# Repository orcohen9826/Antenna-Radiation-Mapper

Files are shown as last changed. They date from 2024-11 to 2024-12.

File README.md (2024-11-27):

# Antenna Radiation Mapper

## Overview

The **Antenna Radiation Mapper** is a versatile tool for mapping antenna radiation patterns with high precision. This project provides an affordable solution for testing antennas, including parabolic reflectors, offering a straightforward setup and simple operation. The system combines automated data collection, precise antenna movement, and easy connectivity, making it ideal for both enthusiasts and professionals looking for an effective antenna testing tool.

Note: This project does not include signal processing features, as they are part of a separate project that cannot be disclosed. Feel free to implement your own signal processing methods if needed.

## Key Features

- **Precision Control:** Rotate the antenna with high precision (approximately 310 steps per degree).
- **Automated Measurements:** Handle sampling, gain calculations, and graph generation.
- **Connectivity:** Connect over WiFi or serial port for data collection.
- **Modular Design:** Easily swap antennas for testing different configurations.

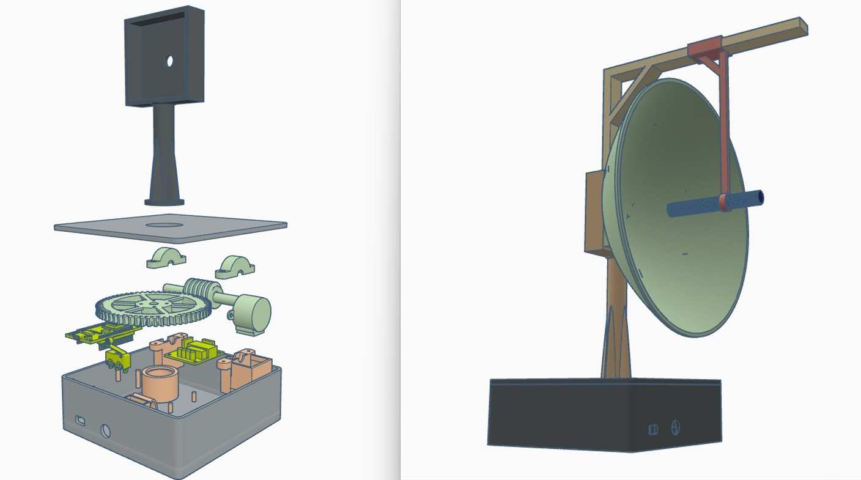
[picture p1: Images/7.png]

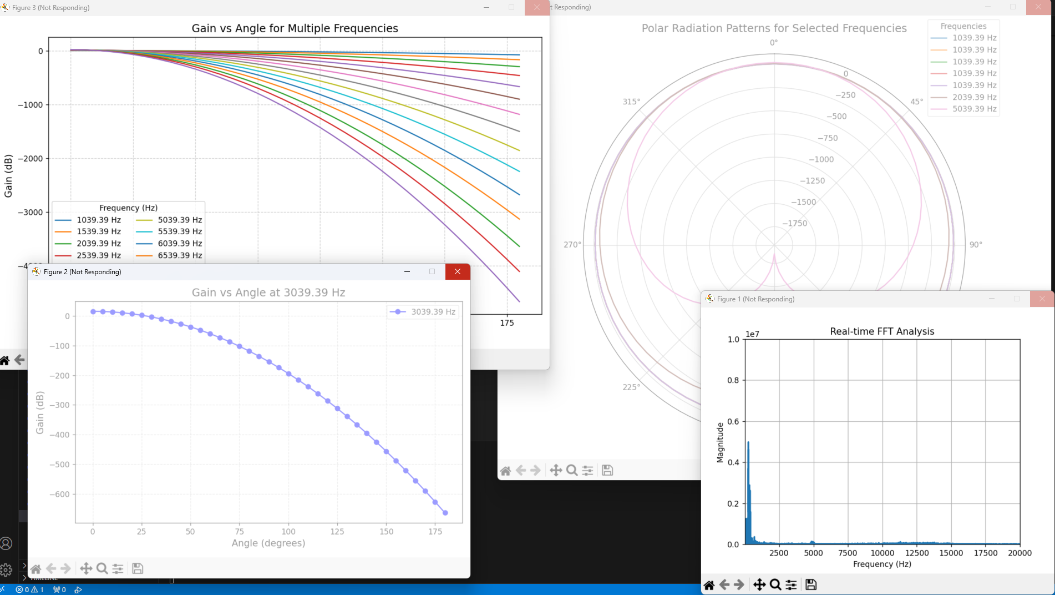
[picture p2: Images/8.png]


## Components Needed

To build your own Antenna Radiation Mapper, you will need the following components:

- **Stepper Motor:**  28BYJ-48
- **Motor Driver:** ULN2003AN
- **Microcontroller:** NodeMCU V3 (ESP8266-based)
- **Bearings:** 4 x Bearings
- **Bolts & Nuts:** 4 x M3*10 Bolts, 4 x M3 Nuts
- **Micro Switch:** 1 Micro Switch

You’ll also need to print some custom-designed 3D parts, which are provided as STL files in the repository.

## Mechanical Setup

1. **3D Print the Required Parts:** Print all parts using the STL files located in the [STL Files Folder](STL_Files).
2. **Attach Bearings:** Insert the 4 bearings into the appropriate printed parts.

## Wiring Instructions

1. **Stepper Motor Wiring:**
   - **IN1:** Connect to pin **D1** on the NodeMCU.
   - **IN2:** Connect to pin **D2** on the NodeMCU.
   - **IN3:** Connect to pin **D3** on the NodeMCU.
   - **IN4:** Connect to pin **D4** on the NodeMCU.

2. **Micro Switch Wiring:**
   - Connect the micro switch to **LIMIT\_SWITCH\_PIN (D5)** on the NodeMCU.

3. **Power Supply:**
   - Provide power to both the driver and the NodeMCU. Ensure that they **share a common ground**.

## Software Setup

1. **Download the Code:** Clone or download the code from this repository.
2. **Microcontroller Code:** Flash the C code to the NodeMCU V3 using [PlatformIO](https://platformio.org/) or the Arduino IDE.
3. **Python Script for Serial Communication:** There is a Python script available in the repository that allows you to connect via serial communication and initiate antenna movements and data recordings.

## Explanation of Files

- **`main.cpp` (Microcontroller Control Code):**
  - This file contains the code for controlling the stepper motor using the NodeMCU. It also provides a web interface accessible at **192.168.4.1** once connected to the WiFi broadcast by the NodeMCU. Users can enter desired angles and control the movement of the antenna through this interface. The script manages commands like moving the antenna, setting a zero (home) position, and pausing.

- **`serial_audio_recorder.py` (Audio Recording and Analysis Script):**
  - This Python script is used to communicate with the microcontroller via serial connection. It listens for commands indicating specific positions (like "Start brake" and "End brake") and then records audio for each of these positions. The script also performs FFT (Fast Fourier Transform) analysis on the recorded audio to determine the frequency response of the antenna and saves these results to a CSV file (`frequency_analysis.csv`).

- **`graphFromCsv.py` (Graph Generation Script):**
  - This script takes the CSV file generated by `serial_audio_recorder.py` and generates graphs to visualize the antenna's performance. It provides functions to plot gain vs. angle for individual frequencies, as well as generate polar radiation patterns. This helps in understanding how the antenna performs at different frequencies and in different directions.

## Getting Started

1. **Power Up:** Make sure the driver, NodeMCU, and micro switch are powered properly.
2. **Connect to WiFi:** Connect to the WiFi network broadcasted by the NodeMCU. Once connected, access the control interface by navigating to **192.168.4.1** in your web browser.
3. **Initiate Testing:** Run the Python script (`serial_audio_recorder.py`) to communicate with the NodeMCU either via WiFi or using a serial connection.
4. **Recording and Analysis:** The Python script will automatically record audio and perform analysis whenever the motor movement pauses. Once testing is complete, the `graphFromCsv.py` script will generate graphs and analyze the antenna's radiation patterns.

## What to Expect

- **Web Interface Control:** You'll be able to control the antenna's movement using a simple web interface. Set the target angle, step size, and delay, and monitor the current position in real-time.
- **Audio Recording and Analysis:** The script records audio at each position, performs FFT to analyze signal properties, and saves the frequency response data to a CSV file.
- **Visual Data Representation:** After collecting data, run the `graphFromCsv.py` script to generate informative visualizations, including gain vs. angle graphs and polar plots. These visualizations will help you evaluate the radiation pattern of the antenna and determine its performance at different frequencies.

## Contributing

If you have any ideas for improving the project, feel free to open a pull request or submit an issue. Contributions are always welcome!

## License

This project is licensed under the MIT License. See the LICENSE file for more details.

## Contact

If you have any questions or issues with the setup, feel free to contact me through GitHub.

Enjoy building your own **Antenna Radiation Mapper**!

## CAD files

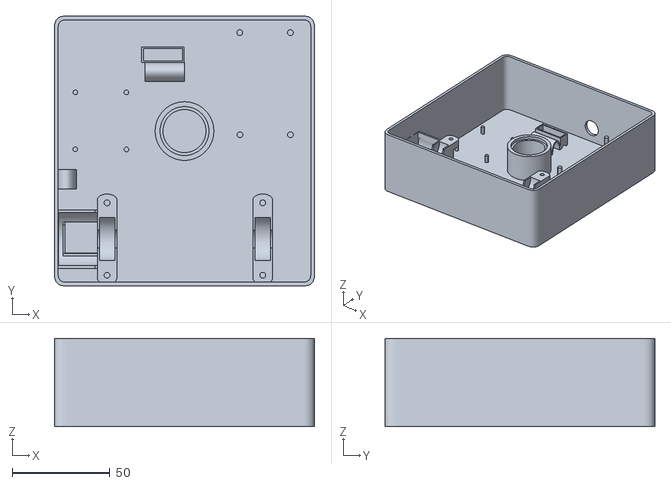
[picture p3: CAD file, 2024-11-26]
STL files/Main Box.stl
133.0 x 138.0 x 45.0

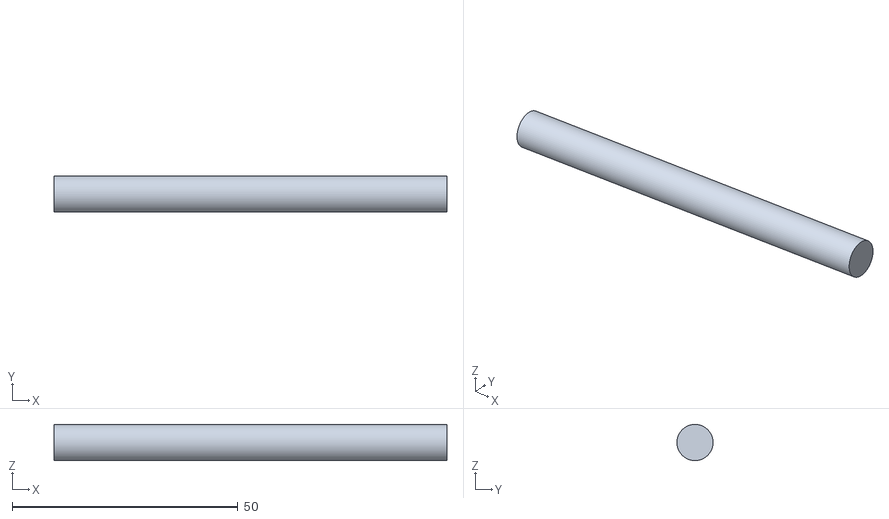
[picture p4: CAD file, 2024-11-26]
STL files/Engine pin.stl
87.0 x 8.00 x 8.00

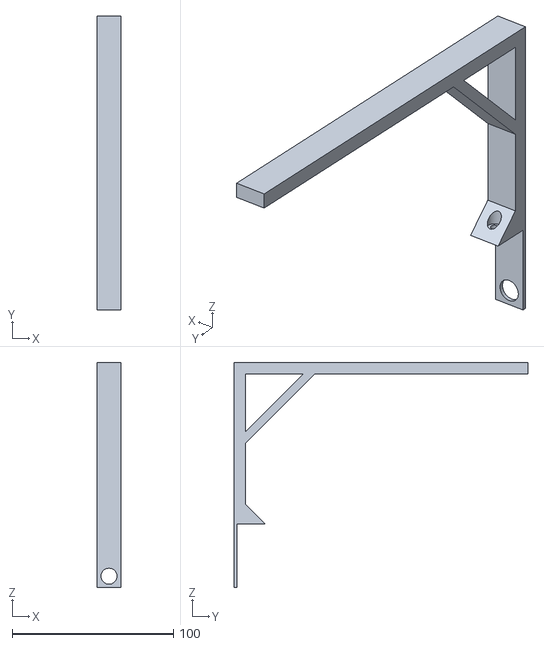
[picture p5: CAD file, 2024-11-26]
STL files/Microphone mount.stl
15.0 x 182.0 x 139.5

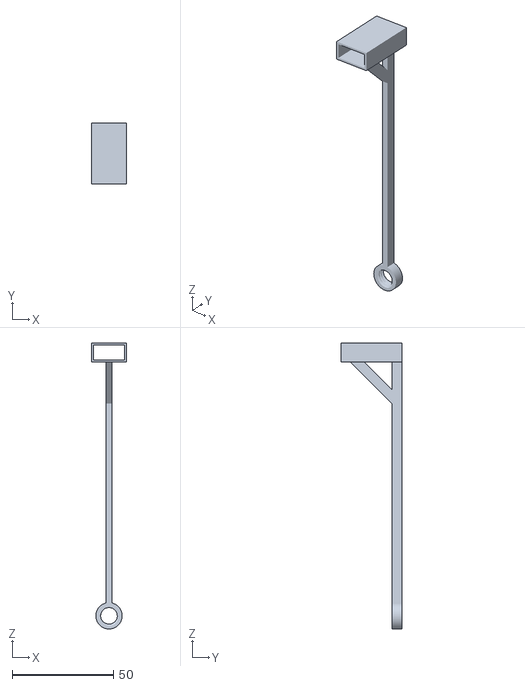
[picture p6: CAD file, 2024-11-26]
STL files/Microphone mount part 2.stl
17.4 x 30.0 x 141.1

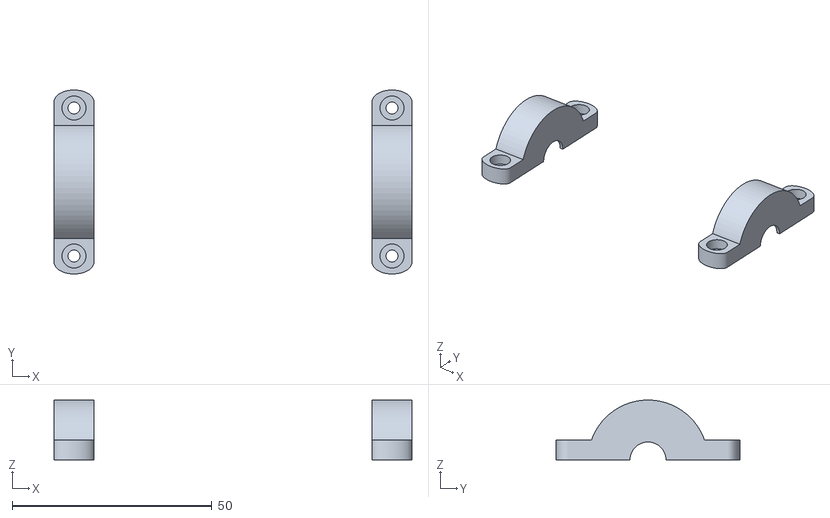
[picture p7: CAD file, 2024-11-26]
STL files/Bearing cover.stl
89.5 x 46.0 x 15.0

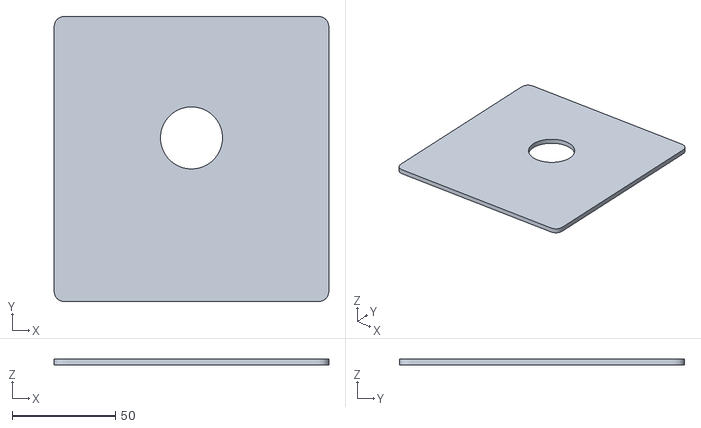
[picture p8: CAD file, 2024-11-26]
STL files/Box Cover.stl
133.0 x 138.0 x 3.00

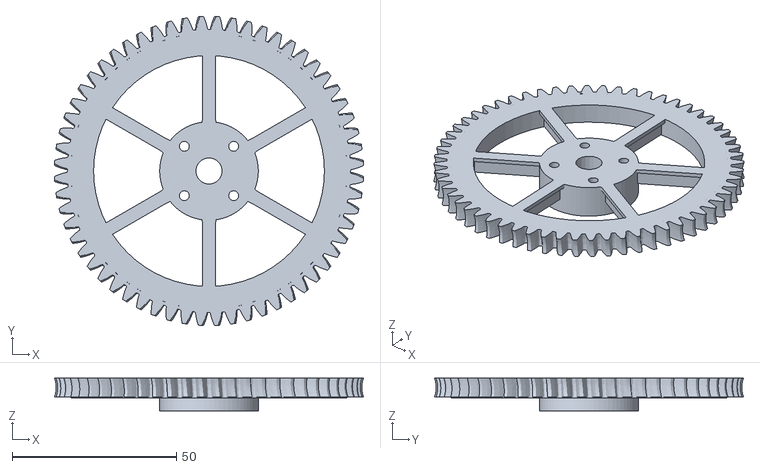
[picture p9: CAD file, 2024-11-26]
STL files/Gear wheel.stl
93.9 x 93.9 x 10.0

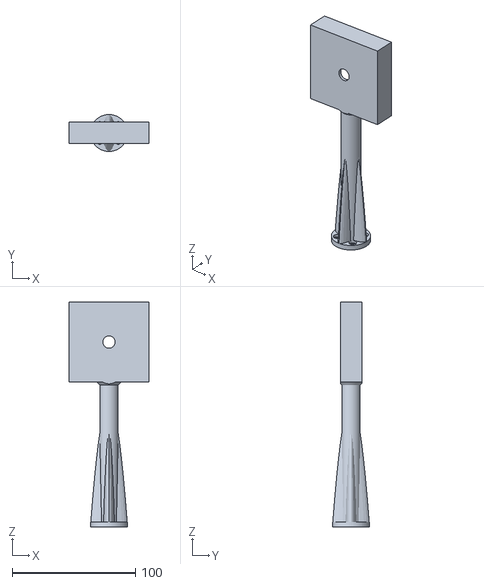
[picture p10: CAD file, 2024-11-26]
STL files/Antenna mount.stl
65.0 x 30.0 x 182.5

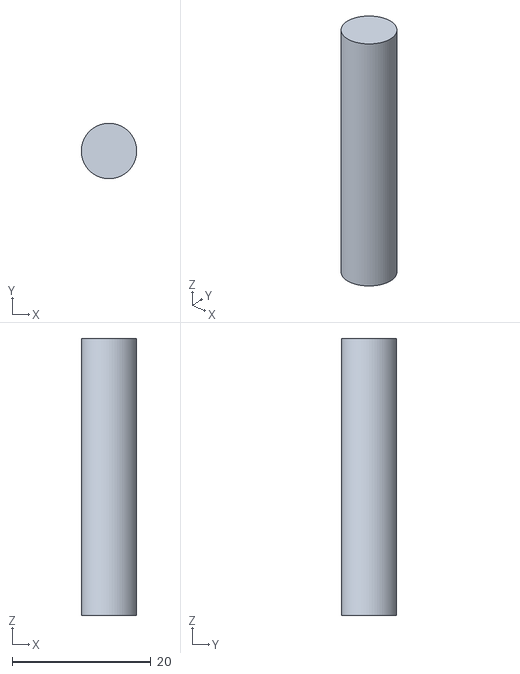
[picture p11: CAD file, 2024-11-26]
STL files/Pin for gear wheel.stl
8.00 x 8.00 x 40.0

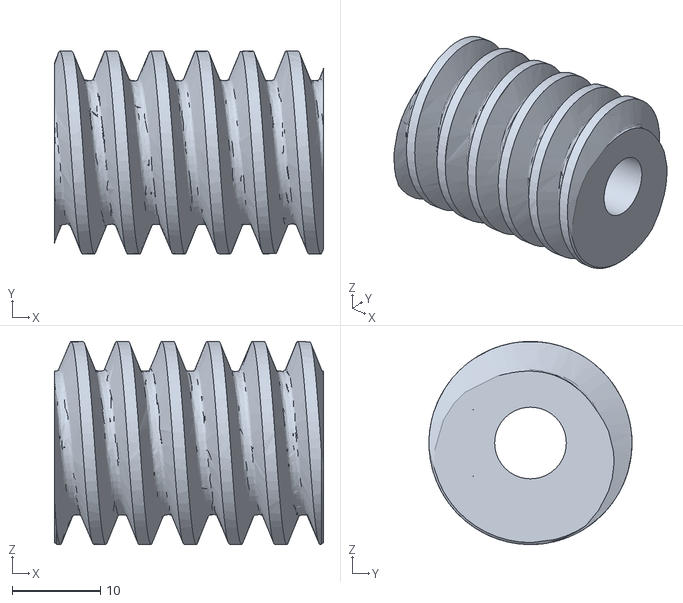
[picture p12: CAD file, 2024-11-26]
STL files/Snail screw.stl
30.5 x 23.0 x 23.0

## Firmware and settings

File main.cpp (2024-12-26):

////////////////////////     DIFFERENT APPROACH HNDLE MOVE FUNCTION  VIA MAIN LOOP //////////////////////////
#include <Arduino.h>
#include <ESP8266WiFi.h>
#include <ESP8266WebServer.h>
#include <Stepper.h>

// WiFi settings
const char* ssid = "StepperControl";
const char* password = "12345678";

// Stepper motor pins for ULN2003 driver
#define IN1 D1
#define IN2 D2
#define IN3 D3
#define IN4 D4
#define LIMIT_SWITCH_PIN D5  // Limit switch for homing

// Movement state
volatile bool isMoving = false;
volatile bool isHomed = false;
volatile float currentPosition = -1; // Current position of the stepper motor


// Steps per revolution for 28BYJ-48 motor
const int STEPS_PER_REVOLUTION = 111550;  // 32 steps per revolution * 64:1 gearbox
const float STEPS_PER_DEGREE = 310 ;//STEPS_PER_REVOLUTION / 360.0;
const bool CALIBRATE = false;

// Initialize stepper motor
Stepper stepper(STEPS_PER_REVOLUTION, IN1, IN3, IN2, IN4);
ESP8266WebServer server(80);

// Movement variables
float targetAngle = 0;
int stepsPerSegment = 0;
unsigned long previousTime = 0;
unsigned long delayTime = 0;
unsigned long vibretion_delay = 800; // a short delay after movment end to insure the system vibration end and radey for quiet recording <1s

// Function declarations
void moveStepper(int steps);
void updateMovement();
long calibrateStepsPerRevolution();
void check_for_handshake_msg();
void customDelay(unsigned long ms);

int flag = 0;

// HTML page with input form
const char* html = R"rawliteral(
<!DOCTYPE html>
<html>
<head>
    <title>Antenna Mapper</title>
    <style>
        body { font-family: Arial, sans-serif; background-color: #f4f4f4; margin: 0; padding: 0; }
        .container { max-width: 600px; margin: 50px auto; background: #fff; padding: 20px; border-radius: 10px; box-shadow: 0 2px 10px rgba(0,0,0,0.1); }
        h1 { text-align: center; color: #333; }
        .input-group { margin: 15px 0; }
        label { display: block; font-weight: bold; margin-bottom: 5px; color: #555; }
        input { width: 100%; padding: 10px; font-size: 16px; border: 1px solid #ddd; border-radius: 5px; }
        button { width: 100%; padding: 10px; font-size: 18px; color: #fff; background-color: #007bff; border: none; border-radius: 5px; cursor: pointer; margin-top: 10px; }
        button.stop { background-color: #ff6b6b; }
        button:hover { opacity: 0.9; }
        #status, #current-position { margin: 15px 0; padding: 10px; background-color: #e9ecef; border-radius: 5px; text-align: center; font-size: 18px; }
    </style>
    <script>
        function checkStatus() {
            fetch('/status')
                .then(response => response.json())
                .then(data => {
                    document.getElementById('status').textContent = 'System Status: ' + data.status;
                    document.getElementById('current-position').textContent = 'Current Position: ' + data.currentAngle.toFixed(2) + '°';
                });
        }

        function sendCommand(endpoint) {
            fetch(endpoint).then(() => checkStatus());
        }

        function startMovement(event) {
            event.preventDefault();
            const formData = new FormData(event.target);
            const params = new URLSearchParams(formData).toString();
            fetch('/move?' + params)
                .then(() => checkStatus());
        }

        setInterval(checkStatus, 1000); // Update status every second
    </script>
</head>
<body>
    <div class="container">
        <h1>Antenna Positioning System</h1>
        <div id="status">System Status: Ready</div>
        <div id="current-position">Current Position: 0°</div>
        <button onclick="sendCommand('/home')">Set Zero Position</button>
        <button onclick="sendCommand('/stop')" class="stop">Emergency Stop</button>
        <form onsubmit="startMovement(event)">
            <div class="input-group">
                <label for="angle">Target Angle:</label>
                <input type="number" id="angle" name="angle" required>
            </div>
            <div class="input-group">
                <label for="stepSize">Step Size:</label>
                <input type="number" id="stepSize" name="stepSize" required>
            </div>
            <div class="input-group">
                <label for="delay">Delay (seconds):</label>
                <input type="number" id="delay" name="delay" required>
            </div>
            <button type="submit">Start Mapping</button>
        </form>
    </div>
</body>
</html>
)rawliteral";

// Web server handlers
void handleRoot() {
    server.send(200, "text/html", html);
}

void handleStatus() {
    String status = "{";
    status += "\"status\":\"" + String(isHomed ? (isMoving ? "Moving" : "Ready") : "Not Homed") + "\",";
    status += "\"currentAngle\":" + String(currentPosition) + "}";
    server.send(200, "application/json", status);
}

void handleStop() {
    isMoving = false;
    digitalWrite(IN1, LOW);
    digitalWrite(IN2, LOW);
    digitalWrite(IN3, LOW);
    digitalWrite(IN4, LOW);
    server.send(200, "text/plain", "Stopped");
}

void handleHome() {
    if (isMoving) {
        server.send(400, "text/plain", "System is currently moving");
        return;
    }

    isMoving = true;
    currentPosition = 0;

    // Move the motor until the limit switch is triggered
    while (digitalRead(LIMIT_SWITCH_PIN) && isMoving) {
        stepper.step(-1);
        delay(5);
    }

    if (isMoving) {
        isHomed = true;
    }

    isMoving = false;
    server.send(200, "text/plain", "Homing complete");
}

void handleMove() {
    if (!isHomed) {
        server.send(400, "text/plain", "Please home the system first");
        return;
    }

    if (isMoving) {
        server.send(400, "text/plain", "System is currently moving");
        return;
    }

    targetAngle = server.arg("angle").toFloat();
    int stepSize = server.arg("stepSize").toInt();
    delayTime = server.arg("delay").toInt() * 1000;

    if (targetAngle <= 0 || stepSize <= 0 || delayTime < 0) {
        server.send(400, "text/plain", "Invalid parameters");
        return;
    }

    server.send(200, "text/plain", "Mapping started");
    isMoving = true;
    stepsPerSegment = round(stepSize * STEPS_PER_DEGREE);
    previousTime = millis();
}

void setup() {
    Serial.begin(9600);
    pinMode(LIMIT_SWITCH_PIN, INPUT_PULLUP);
    WiFi.softAP(ssid, password);

    server.on("/", handleRoot);
    server.on("/move", handleMove);
    server.on("/home", handleHome);
    server.on("/stop", handleStop);
    server.on("/status", handleStatus);

    //caibration
    if(CALIBRATE){
        long stepsPerRevolution = calibrateStepsPerRevolution();
        Serial.println("Calibration complete");
        Serial.printf("Steps per revolution: %ld\n", stepsPerRevolution);
    }


    server.begin();
    stepper.setSpeed(10);
    isHomed = false;
    isMoving = false;
    
}

void customDelay(unsigned long ms) {
    unsigned long start = millis();
    while (millis() - start < ms) {
        yield();
    }
}

// Update motor movement in loop
void updateMovement() {

    if (isMoving && currentPosition < targetAngle) {
        if (currentPosition ==0){//on first move send recognition msg and start msg
            // let the recorder to record the first position
            Serial.printf("Start brake, current position: %.2f\n", 0.0);
            delay(delayTime);
        }
        // Check if the elapsed time is greater or equal to the delay time set
        if (millis() - previousTime >= delayTime) {

            Serial.printf("End of brake");                       
            // Update the current position and move the stepper motor
            currentPosition += stepsPerSegment / STEPS_PER_DEGREE;
            moveStepper(stepsPerSegment);
            // whait short time for wibaration to end
            customDelay(vibretion_delay);
            // Print a message indicating the start of the delay after moving the stepper
            Serial.printf("Start brake, current position: %.2f\n", currentPosition);
             // Update the last step time
             previousTime = millis();
        }
        

        // yield() allows background tasks (e.g., WiFi tasks) during the wait
        yield();
    }

    // Stop moving if target angle is reached
    if ((currentPosition >= targetAngle)&&isMoving) {
        isMoving = false;
        Serial.println("Movement complete");
    }
}

void moveStepper(int steps) {
    for (int i = 0; i < steps; i++) {
        stepper.step(1);
        delay(5);
    }
}

long calibrateStepsPerRevolution() {
    //first set home and than counting to reach home again means it completed one revolution if set home again(it circled so it reach the micro switc again)
    //then count the steps and divide by 360 to get the steps per degree
    while(digitalRead(LIMIT_SWITCH_PIN)){
        stepper.step(-1);
        delay(5);
    }
    moveStepper(100);
    long count = 100;
    while(digitalRead(LIMIT_SWITCH_PIN)){
        stepper.step(1);
        delay(5);
        count++;
    }

    return count;
}

void check_for_handshake_msg(){
    //check for the handshake message
    //if "recorder handshaked" is received then  react with "mapper handshaked"
    String handshake_msg = "Recorder handshaked";
    if(Serial.available() > 0){
        String msg = Serial.readString();
        msg.trim();
        
    
        if(msg == handshake_msg){
            Serial.printf("Mapper handshaked\n");
            flag = 1;
        }
    }
}

void loop() {
    server.handleClient();
    updateMovement();
    if(flag == 0);{ 
        check_for_handshake_msg();
    }
}

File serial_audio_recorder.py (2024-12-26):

import serial
import time
import sounddevice as sd
import numpy as np
import wave
import serial.tools.list_ports
import threading
import csv
import os
import queue
from scipy.fft import fft
import matplotlib.pyplot as plt
from graphFromCsv import plot_polar_radiation_pattern , plot_gain_vs_angle , plot_gain_for_all_frequencies , plot_polar_radiation_pattern

# Serial port settings
SERIAL_PORT = None
BAUD_RATE = 9600

# Audio recording settings
SAMPLE_RATE = 44100  # Sample rate in Hz
CHANNELS = 1  # Mono recording

# Default frequency list for analysis 100 hz to 20khz with 100 hz interval
DEFAULT_FREQUENCIES = range(100, 20001, 100)  # Hz
CUT_OFF_FREQUENCY = 2000
CSV_FILENAME = "frequency_analysis.csv"
FREQUENCIES_TO_PLOT = [100, 500, 1000, 2000, 5000, 10000, 20000] # Hz , frequencies to plot in polar radiation pattern

# Queue for FFT data to be processed by the main thread
fft_queue = queue.Queue()

# Create a persistent figure and axis for real-time FFT updates
plt.ion()  # Turn on interactive mode for updating the plot
fig, ax = plt.subplots()
line, = ax.plot([], [], lw=2)
ax.set_xlabel('Frequency (Hz)')
ax.set_ylabel('Magnitude')
ax.set_title('Real-time FFT Analysis')
ax.grid()

# Set limits for initial plot
ax.set_xlim(20, 20000)  # Adjust frequency range from 20 Hz to 20 kHz
ax.set_ylim(0, 10000000)  # Adjust to an exponent of 7 for magnitude range
ax.set_xscale('linear')  # Set the x-axis to a linear scale

# Function to find and initialize the serial port supporting Custom handshake protocol
def find_and_init_serial_port():
    '''send to each port a hndshake message "Recorder handshaked" and wait for a " Mapper handshaked " message to confirm the port'''
    attempts = 3
    for port in serial.tools.list_ports.comports():
        print(f"Trying port: {port.device}")
        for _ in range(attempts):
            try:
                #if ser already open close it
                if 'ser' in locals() or 'ser' in globals():
                    ser.close()
                ser = serial.Serial(port.device, BAUD_RATE, timeout=1 , write_timeout=1)
                time.sleep(2)  # Wait for the serial connection to initialize
                print(f"looking for handshake on port: {port.device}")
                #timout for write is 1 second
                ser.write("Recorder handshaked".encode())
                time.sleep(1)
                if ser.in_waiting > 0:
                    try:
                        line = ser.readline().decode('utf-8').strip()
                        if "Mapper handshaked" in line:
                            print(f"Connected Successfully to serial port: {port.device}")
                            return ser
                    except UnicodeDecodeError:
                        
                        pass
            
            except serial.SerialException as e:
                print(f" Could not open serial port {port.device}. {e}")

        ser.close()    
    return None
                
# Function to record audio from the default microphone
def record_audio(filename, duration):
    """Record audio from the microphone for the given duration and save it to a file."""
    print(f"Recording audio for {duration} seconds...")
    audio_data = sd.rec(int(duration * SAMPLE_RATE), samplerate=SAMPLE_RATE, channels=CHANNELS, dtype=np.int16)
    sd.wait()  # Wait until the recording is finished
    
    # Save the recording to a WAV file

    with wave.open(filename, 'wb') as wf:
        wf.setnchannels(CHANNELS)
        wf.setsampwidth(2)  # 16-bit audio
        wf.setframerate(SAMPLE_RATE)
        wf.writeframes(audio_data.tobytes())
    print(f"Audio saved as {filename}")

# Function to analyze audio in a separate thread
def analyze_audio_thread(filename, frequencies=DEFAULT_FREQUENCIES):
    """Thread to analyze audio once the recording is complete."""
    analysis_thread = threading.Thread(target=analyze_audio, args=(filename, frequencies))
    analysis_thread.start()

# Function to analyze audio using FFT
def analyze_audio(filename, frequencies=DEFAULT_FREQUENCIES):
    """Perform FFT on the recorded audio and put the results in the queue for main thread processing."""
    # Load audio file
    with wave.open(filename, 'rb') as wf:
        n_channels = wf.getnchannels()
        sampwidth = wf.getsampwidth()
        framerate = wf.getframerate()
        n_frames = wf.getnframes()
        audio_data = wf.readframes(n_frames)
        audio_data = np.frombuffer(audio_data, dtype=np.int16)
    
    # Perform FFT
    fft_result = fft(audio_data)
    freqs = np.fft.fftfreq(len(fft_result), d=1/SAMPLE_RATE)
    magnitudes = np.abs(fft_result)
    
    # Filter frequencies between 20 Hz and 20 kHz
    valid_indices = np.where((freqs >= 20) & (freqs <= 20000))
    freqs = freqs[valid_indices]
    magnitudes = magnitudes[valid_indices]
    
    # Put FFT results in the queue
    fft_queue.put((freqs, magnitudes, filename, frequencies))

# Function to update the FFT live plot with new data
def update_plot(freqs, magnitudes):
    """Update the FFT plot with the new data."""
    ax.set_xlim(20, 20000)  # Set frequency range from 20 Hz to 20 kHz
    line.set_data(freqs, magnitudes)
    ax.relim()  # Recalculate limits for the new data
    ax.autoscale_view()  # Autoscale the view to fit the new data
    fig.canvas.draw()
    fig.canvas.flush_events()

# Function to save extracted frequency data to a CSV file
def save_to_csv(data, frequencies):
    """Save the extracted frequency data to a CSV file."""
    header = ["Angle (degrees)"] + [f"{int(freq)} Hz" for freq in frequencies]
    file_exists = os.path.isfile(CSV_FILENAME)
    
    with open(CSV_FILENAME, mode='a', newline='') as file:
        writer = csv.writer(file)
        if not file_exists:
            writer.writerow(header)
        writer.writerow(data)

# Function to rename the CSV file after movement is complete
def rename_recordings():
    """Prompt the user to rename the CSV file when movement is complete."""
    global CSV_FILENAME
    new_name = input("Movement complete. Enter a new name for the CSV file (without extension): ")
    if new_name:
        new_filename = f"{new_name}.csv"
        folder_name = os.path.dirname(CSV_FILENAME)
        new_filename = os.path.join(folder_name, new_filename)
        os.rename(CSV_FILENAME, new_filename)
        CSV_FILENAME = new_filename
        print(f"CSV file renamed to {new_filename}")
        # Plot radiation patterns after renaming the file
        plot_csv_data(CSV_FILENAME)

# Function to plot at the end of the program the csv data
def plot_csv_data(CSV_FILENAME):
        plot_gain_vs_angle(CSV_FILENAME,CUT_OFF_FREQUENCY)
        plot_gain_for_all_frequencies(CSV_FILENAME)
        plot_polar_radiation_pattern(CSV_FILENAME, FREQUENCIES_TO_PLOT)
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

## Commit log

2024-11-26 Add STL Files
    [Antenna mount.stl, Bearing cover.stl, Box Cover.stl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]
2024-12-26 Update main.cpp
    Enhanced handshake response and noise protection
    - Added logic to respond to the "Recorder handshaked" message from the Python script with a "Mapper handshaked" message, confirming the handshake.
    - Introduced a sub-second delay to mitigate noise and vibrations, ensuring stable and reliable communication.
    [main.cpp]
